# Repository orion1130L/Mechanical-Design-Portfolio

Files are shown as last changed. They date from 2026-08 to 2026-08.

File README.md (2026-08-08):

# Mechanical-Design-Portfolio
# 个人机械设计作品集

本仓库收录了我独立完成的机械系统设计项目。

## 项目一：平行连杆夹爪

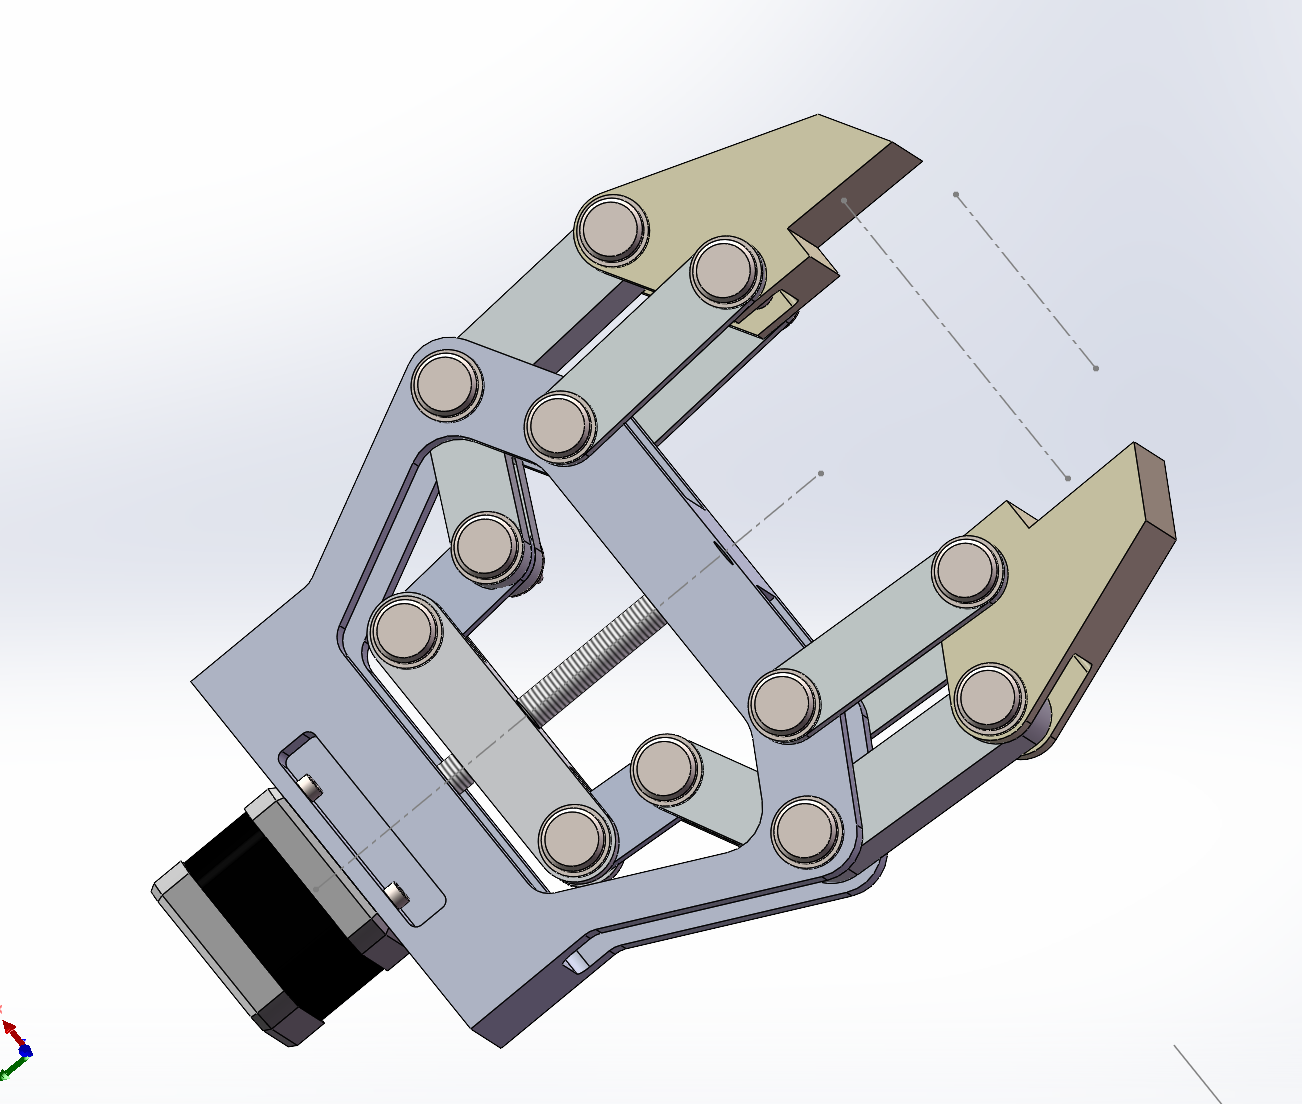
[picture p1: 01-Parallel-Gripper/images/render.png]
夹爪渲染图


- **技术方案**：四杆联动机构 + NEMA17步进电机丝杠驱动
- **设计成果**：行程50-80mm，额定夹持力32.6N，整机安全系数2.5
- **关键工作**：运动学优化、紧固件选型校核、静力学仿真验证

[查看完整设计报告](./01-Parallel-Gripper/docs/机械平行夹爪说明书.pdf)
[查看模型](./01-Parallel-Gripper/models/assembly.IGS) | 通用格式，所有CAD软件可打开 |
## 项目二：滤筒壳体

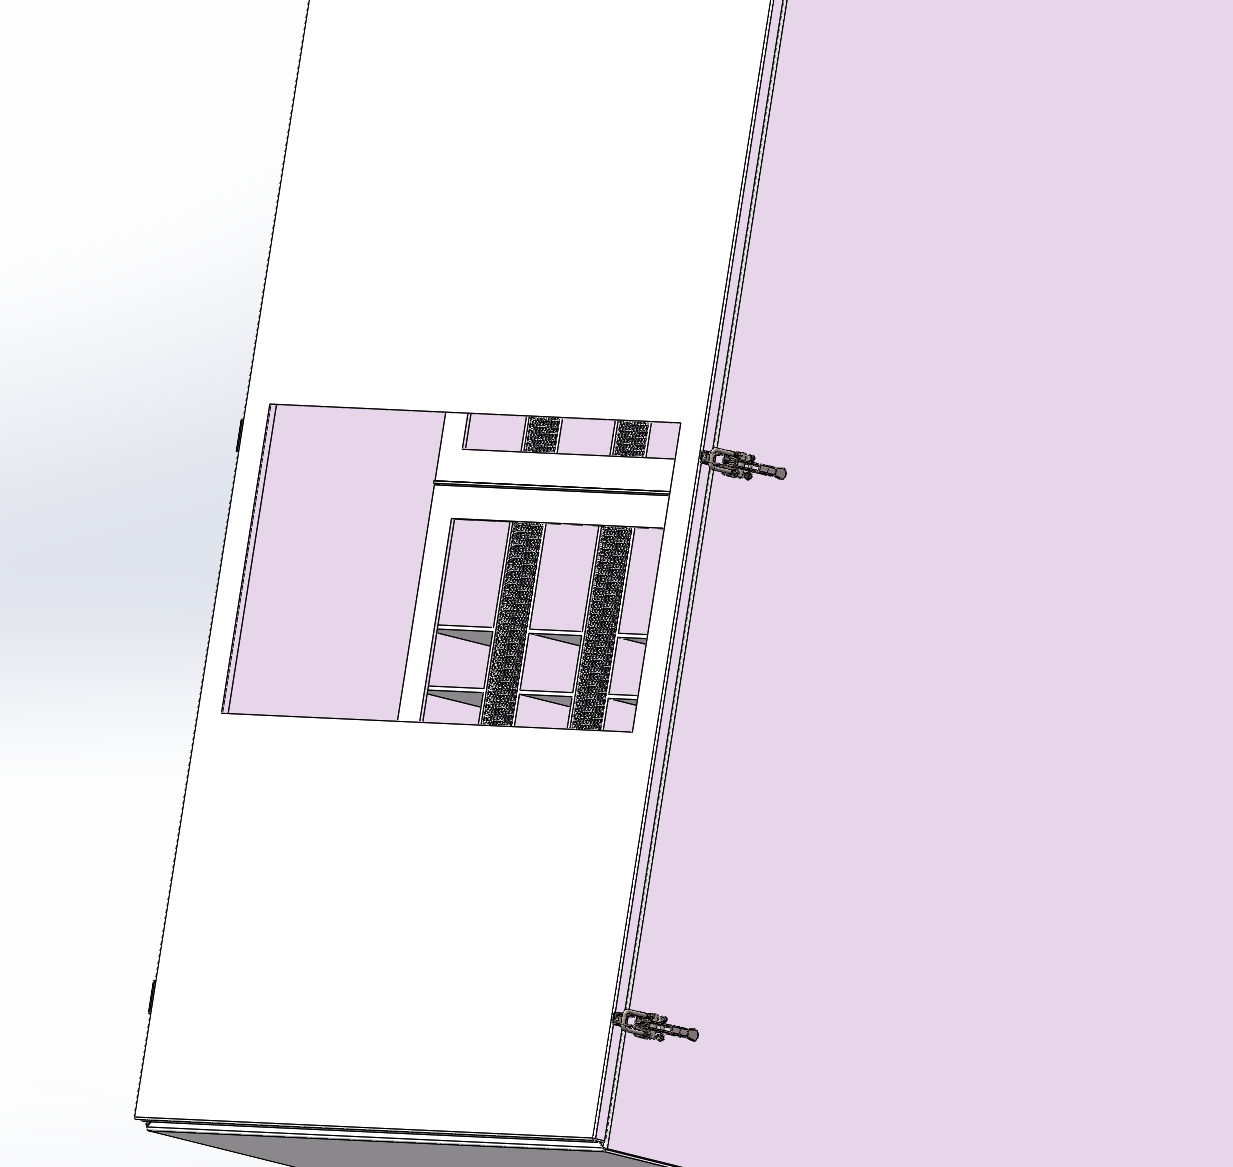
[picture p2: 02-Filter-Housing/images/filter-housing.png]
滤筒壳体


## 关于我

机械工程背景，对机器人末端执行器与柔顺机构设计感兴趣。

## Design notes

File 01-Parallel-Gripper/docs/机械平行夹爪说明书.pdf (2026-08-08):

## 机械平行夹爪说明书

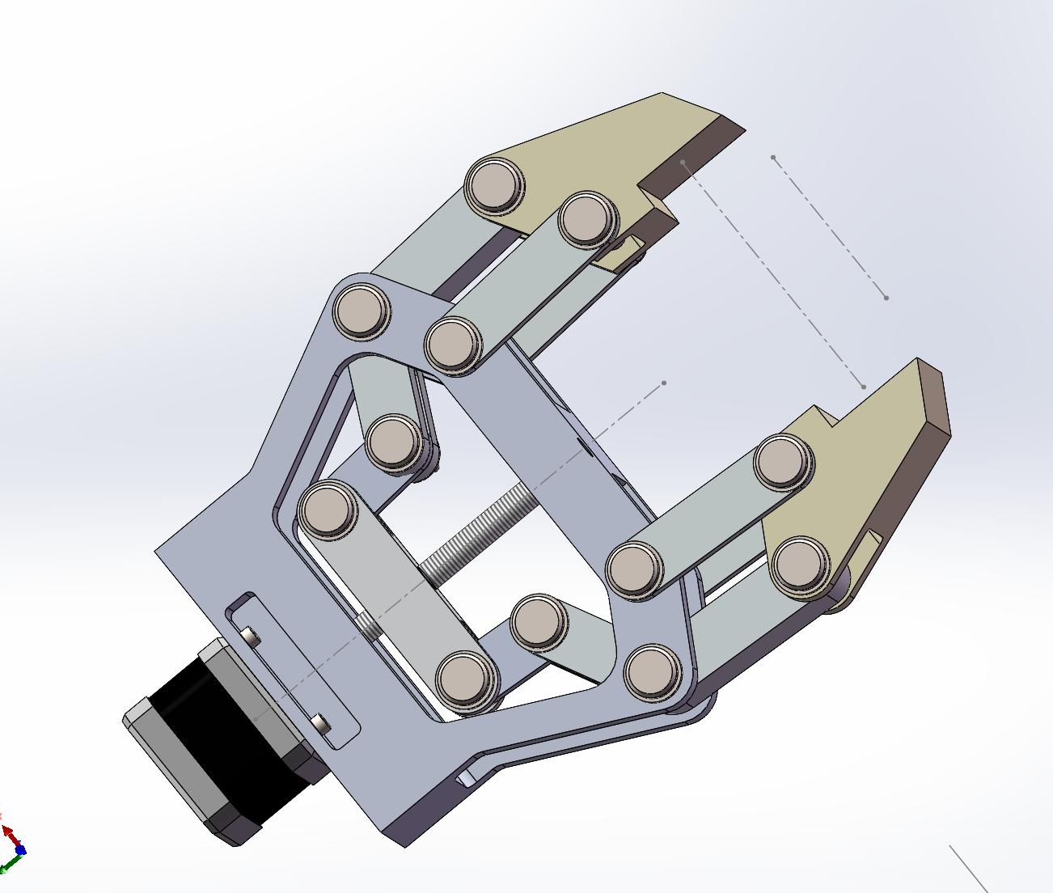
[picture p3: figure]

一，项目名称：桌面级高精度平行连杆夹爪研发

技术方案：采用四杆联动机构与步进电机丝杠一体化传动设计。

核心功能：该项目旨在设计一款具备高重复定位精度的平行开合夹

爪，抓取行程覆盖 50mm 至 80mm。通过 NEMA 17 线性执行器（丝

杠电机）驱动，实现了结构紧凑化设计。项目重点解决了连杆机构

的运动学仿真、标准件选型冗余校核以及复杂装配环境下的紧固连

接可靠性问题。

二，项目职责：

1. 机构建模与运动学优化：使用 SolidWorks 完成全系统参数化建

模。通过理论推导与仿真校核，将连杆中心距从理论值 59.968mm

优化圆整为 60mm，在保证平行开合精度的前提下，显著降低了零件

的机加工工艺难度（DFM 优化）。

2. 紧固与传动系统设计：独立完成驱动端装配方案设计。针对

12.6mm 的大厚度叠层结构，通过紧固件堆叠分析，舍弃了导致结构

薄弱的深沉头设计，选定 ISO 4762 M3x16 规格螺钉。

3. 装配可行性评估：针对旋转关节的轴向限位问题，进行了三轮尺

寸迭代。通过对平垫圈与开口销孔位的空间包络分析，将销轴长度

精确定义为 35mm，确保了装配过程的便捷性与长期运行的维护可靠

性。

三，项目业绩：

1. 设计标准化与工程化：实现了全机标准件 100% 遵循 ISO/GB 标

准规范，显著提升了 BOM 清单的采购兼容性与后期维护的互换性。

2. 关键连接点安全校核：精确控制电机端螺纹啮合深度为 3.4mm

（约 1.1D），在确保连接强度的同时，实现了螺钉末端与电机内部

定子线圈的安全避让，从设计源头规避了电气损毁风险。

3. 技术文档交付：独立完成了包含爆炸图、物料清单 (BOM) 及关

键零件加工图在内的完整技术包，展示了从概念设计到可制造化全

流程掌控能力。

【附录 A：抓取目标与材料选型】

1. 目标工况定义

抓取对象：以标准金属圆柱加工件 / 3C 制造产线电机外壳为例

尺寸范围：外径 Φ60mm ~ Φ70mm（落入 50 ~ 80mm 的有效行程

区）

额定负载质量 (M)：1.0kg

2. 核心部件材料分配

夹爪指尖：表面贴附聚氨酯 (PU) 橡胶软垫（静摩擦系数取 0.3），

提供防滑及微量形变保护。

平行连杆机构：选用 6061-T6 铝合金（CNC 加工），具备优异的屈

服强度与较低的质量，中心孔铰制 Φ8 H7 精度。

固定底座：选用 PETG 或 PA12 工业级树脂 3D 打印，满足厚度结

构的刚度要求。

【附录 B：夹持力学与摩擦力校核】

以标准金属圆柱加工件 / 3C 制造产线电机外壳为例，计算夹持

1kg 负载所需的目标力，并引入动载安全系数。

1. 重力计算

G = M * g = 1kg * 9.8m/s^2 = 9.8N

2. 所需静摩擦力与法向夹紧力

两侧夹爪提供的静摩擦力总和必须大于等于重力。单侧需提供的摩

擦力为 f = 4.9N。

基于 PU 橡胶与金属的摩擦系数 0.3，计算单侧理论法向夹紧力：

理论夹紧力 = f / 0.3 = 4.9N / 0.3 ≈ 16.3N

3. 工程安全余量校核

考虑到机械臂末端可能存在高加速度抖动，引入动载安全系数 K =

2.0。

实际所需夹持力 = 理论夹紧力 * 2.0 = 16.3N * 2.0 = 32.6N

结论：夹爪末端需至少输出 32.6N 的单侧夹持力。

【附录 C：动力传动与步进电机扭矩反推】

该夹爪采用 NEMA 17 一体化丝杠步进电机（匹配梯形丝杠，导程

P=2mm）。通过虚功原理及螺旋传动方程，结合实际三维模型测得的

运动学参数，反推所需的电机保持扭矩。

1. 连杆推力转换（基于实际工作位姿）

根据 SolidWorks 模型实际测定，在设定的极限抓取姿态下，滑块

轴向位移量 Δx = 5.53mm 时，单侧指尖横向位移量 Δy = 15mm。

此时机构的位移传动比：Δy / Δx = 15 / 5.53 ≈ 2.712

根据虚功原理（忽略摩擦损耗），输入功等于总输出功。驱动丝杠需

提供的总轴向推力为：

轴向推力 = 2 * 实际所需夹持力 * (Δy / Δx)

轴向推力 = 2 * 32.6N * 2.712 = 176.8N

2. 螺旋传动扭矩计算

将轴向直线推力转化为电机的旋转扭矩。查阅梯形丝杠传动设计手

册，取传动效率为 0.35。

所需扭矩 = (轴向推力 * 导程) / (2 * 3.14 * 传动效率)

所需扭矩 = (176.8N * 0.002m) / (2 * 3.14 * 0.35) ≈ 0.161

N·m

3. 选型闭环结论

理论需求值：在极限满载且处于最费力传动比（2.712）的工况下，

机构需电机输出 0.161 N·m 的运行扭矩。

实际供给值：本设计选用的 40mm 机身长 NEMA 17 步进电机，其额

定保持扭矩约为 0.40 N·m。

安全系数闭环：0.40 / 0.161 ≈ 2.48 倍。

最终判定：本机构在最恶劣工况下的动力系统依然存在近 2.5 倍的

安全冗余。整机驱动系统校核合格，从根本上杜绝了因负载波动导

致电机“丢步”或堵转的工程风险。一. 设计背景与目标 (Design

Requirements)

【附录 D：概念设计】

平行四边形原理：采用双对称平行四边形连杆结构。相比单连杆，

该结构能确保抓取面受力均匀，避免在抓取轻薄物体时产生滑脱。

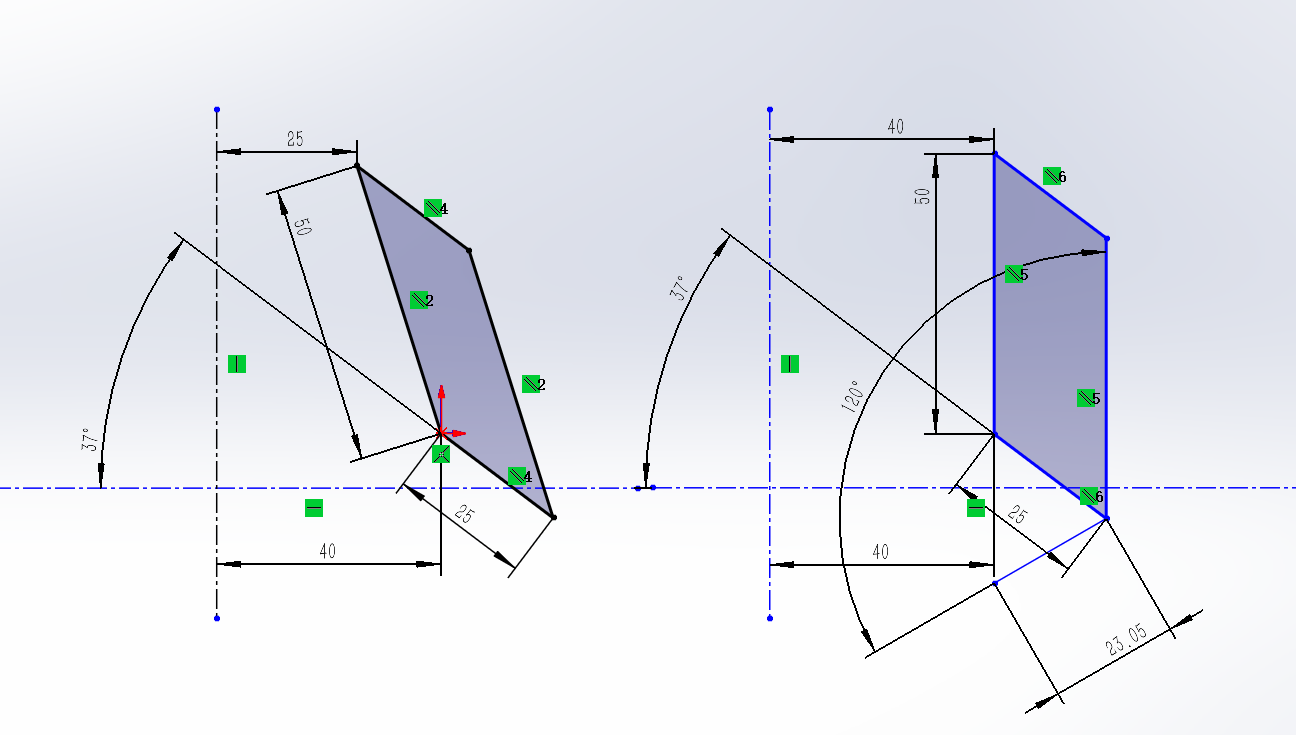
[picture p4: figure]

【附录 E：应力分析】

1，针对受力最苛刻的夹爪指尖(6061 铝合金)，在 32.6N 额定极限

夹持力下进行单体静力学仿真。

边界条件设定:顶部两连接孔采用固定铰链约束，模拟销轴承载状

态。

应力分析结果:最大应力发生于上端销孔内壁(约 7.58MPa)，远低于

6061 铝合金的屈服强度(55.15 MPa).

校核结论:结构安全系数高达 7.2，具备充足的刚度与强度冗余，彻

底排除指尖断裂或塑性变形风险，满足高频工业抓取需求。

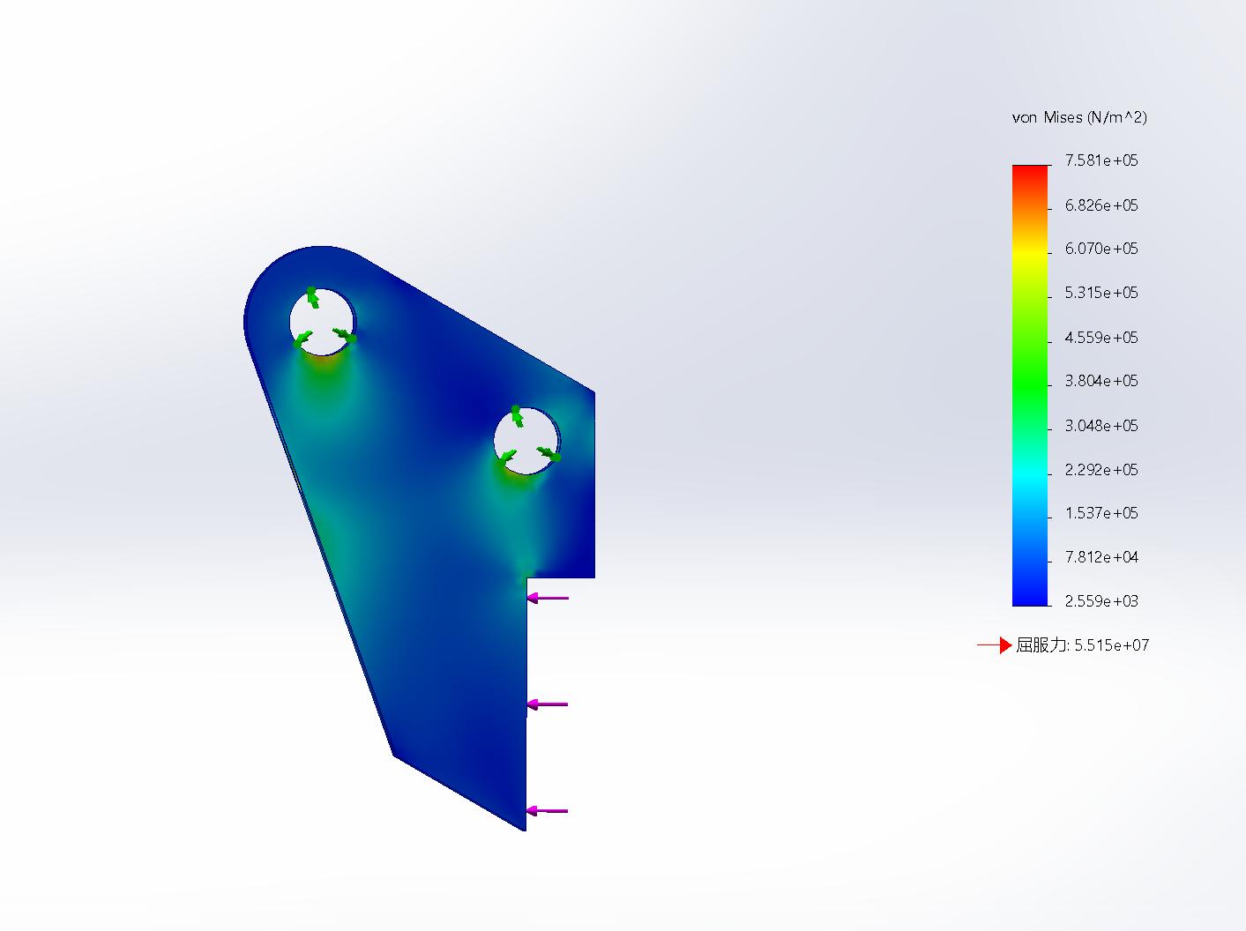
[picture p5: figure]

2.滑块静力学仿真验证

在施加 176.8N 的满载轴向推力工况下，对中心传动滑块进行了应力

分析。仿真结果表明:

应力集中主要出现在中心传力螺纹孔根部，符合载荷传递规律。

全局最大等效应力为 11.03MPa。

对比 6061-T6 铝合金 275MPa 的屈服强度，该零件在满载下的安全系

数高达 25。结论:结构刚度完全满足要求，无疲劳或屈服失效风

险。后期若需整机轻量化，该处横梁厚度仍有极大的优化(掏空/减

薄)空间

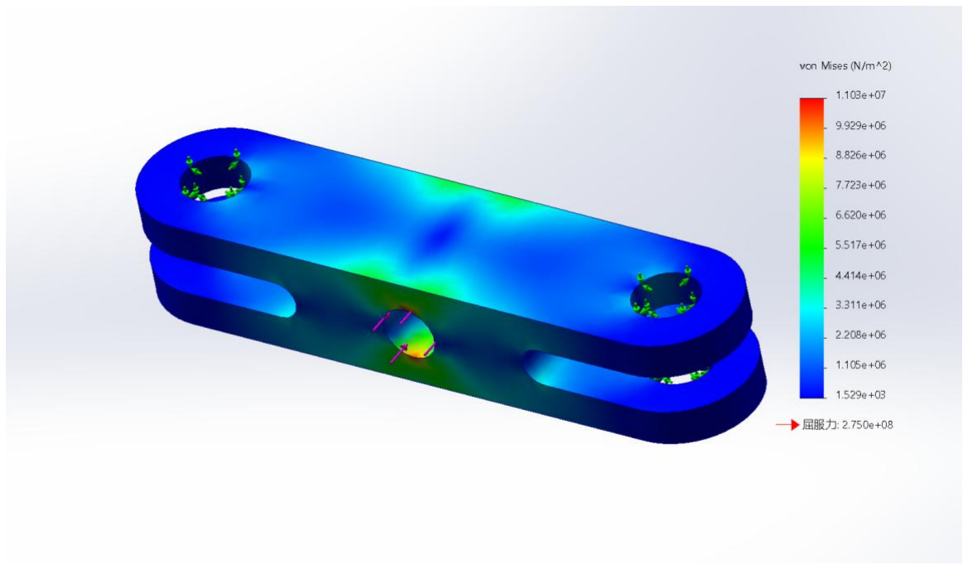
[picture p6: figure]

3，在施加 80N 的满载轴向推力工况下，对关键零件 1 号连杆进行了

应力分析

仿真结果表明:

全局最大等效应力为 81.01MPa。

对比 6061-T6 铝合金 275MPa 的屈服强度，该零件在满载下的安全系

数为 3，下端孔合力为 115N，符合爪头受力要求

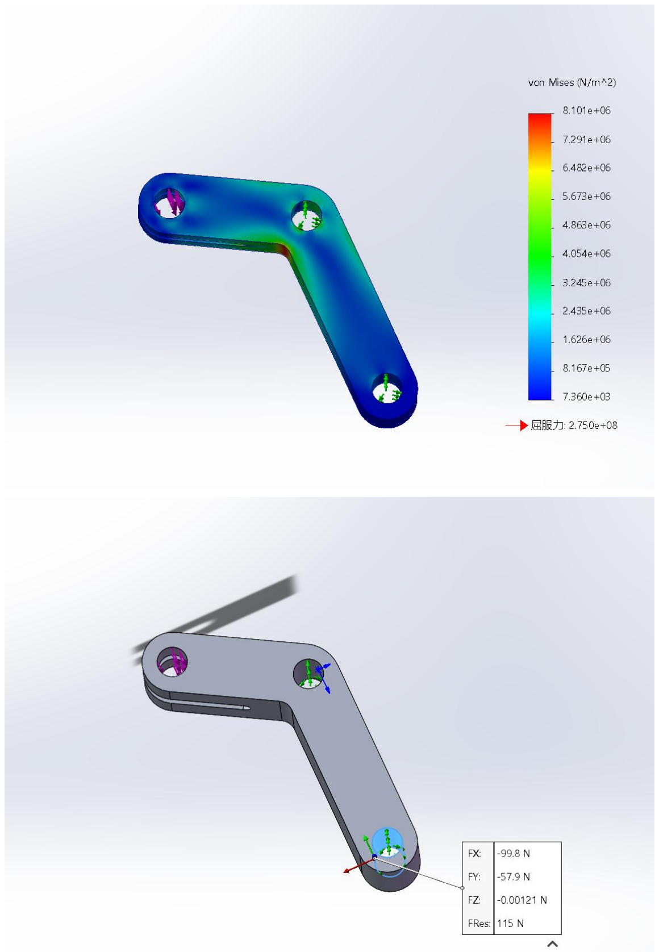
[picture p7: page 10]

【附录 F：爆炸图】

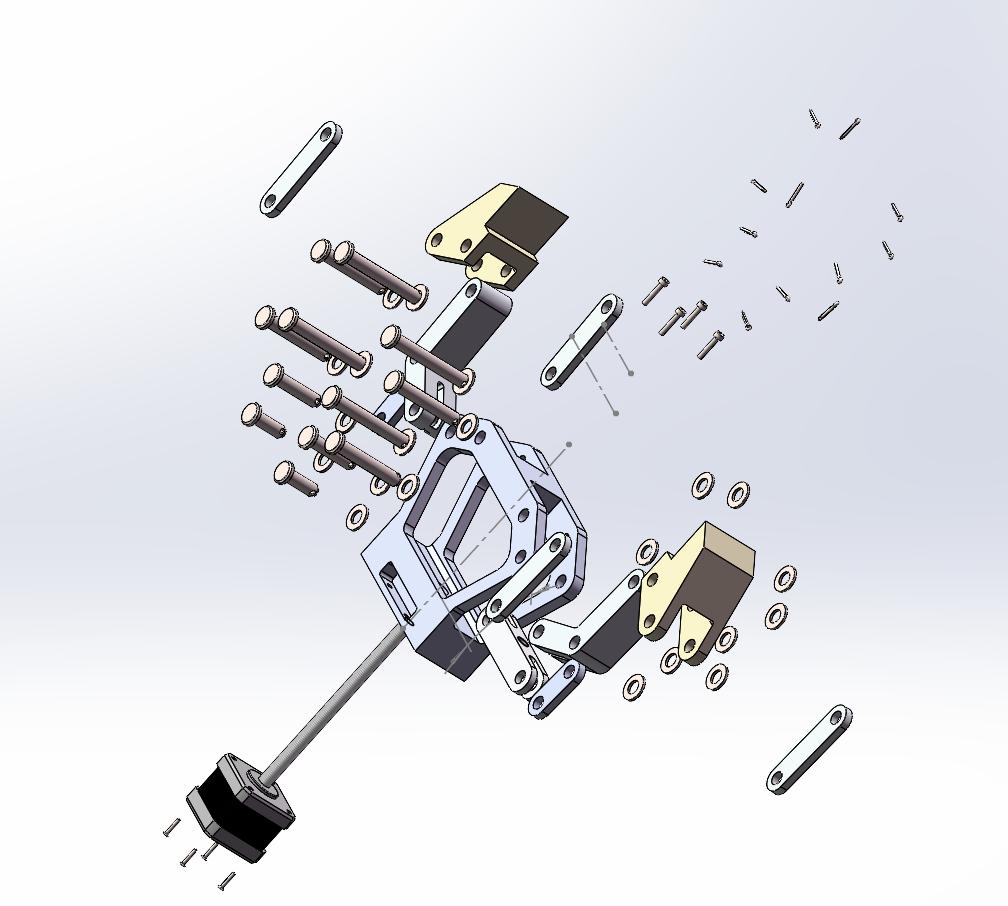
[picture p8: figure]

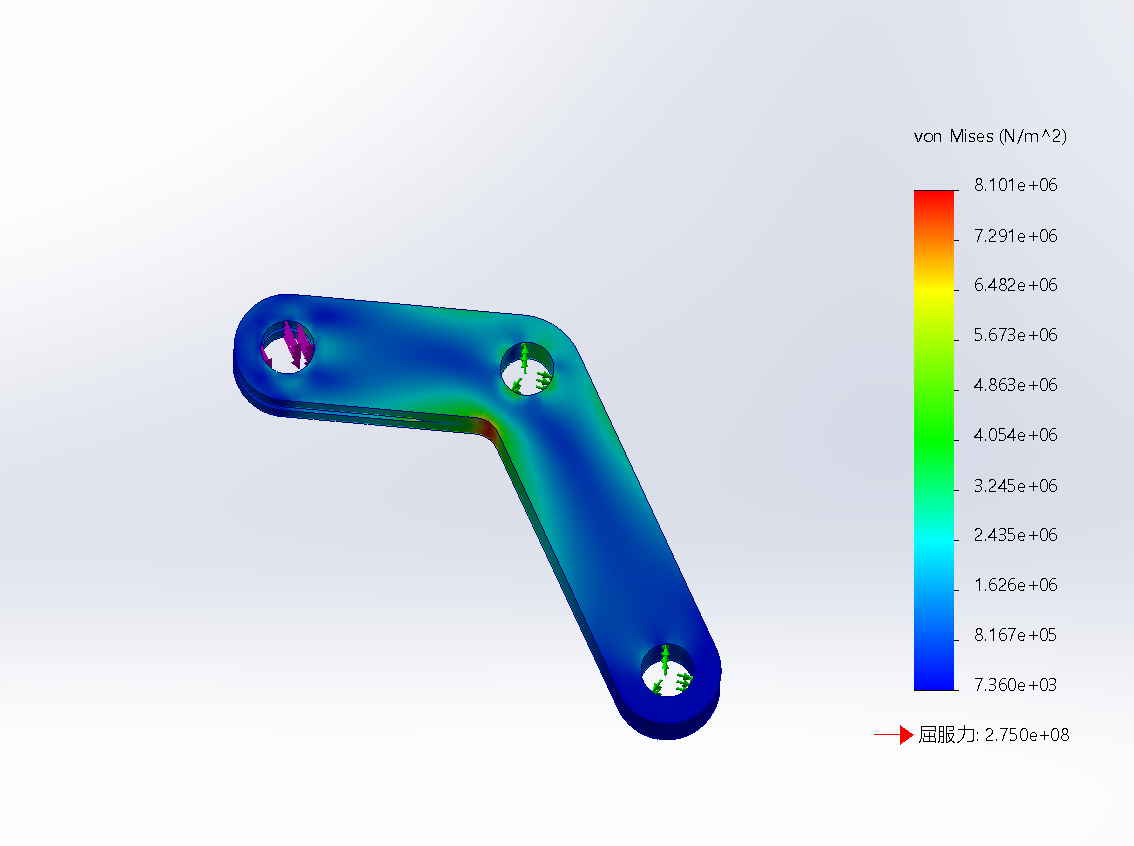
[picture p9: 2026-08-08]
01-Parallel-Gripper/simulations/connecting rod.png

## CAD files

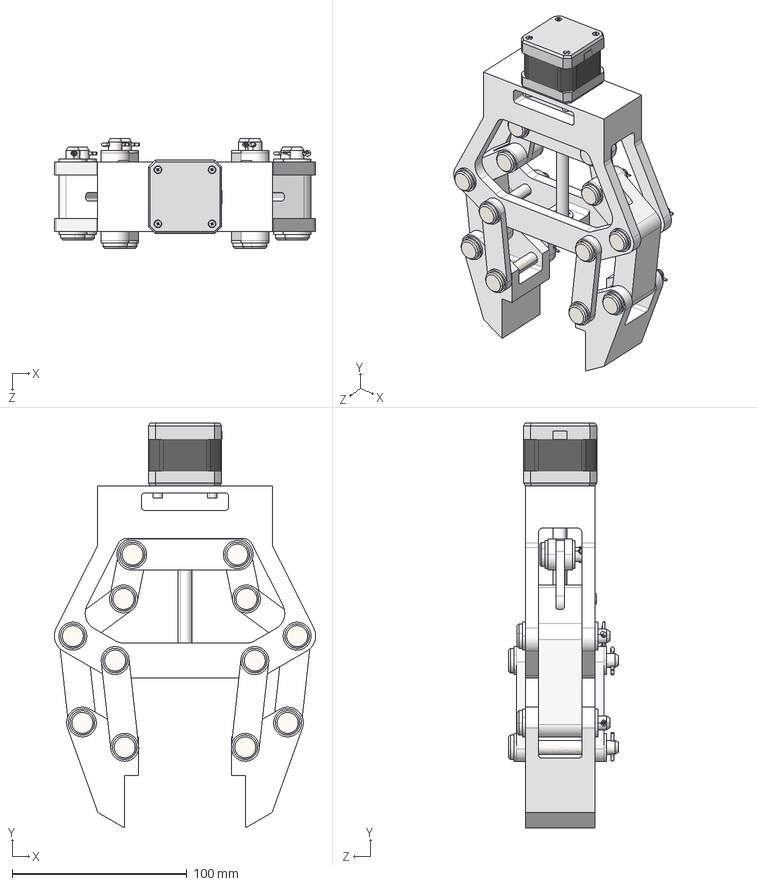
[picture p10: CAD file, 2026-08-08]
01-Parallel-Gripper/models/assembly.IGS
149.7 x 232.0 x 63.0 mm

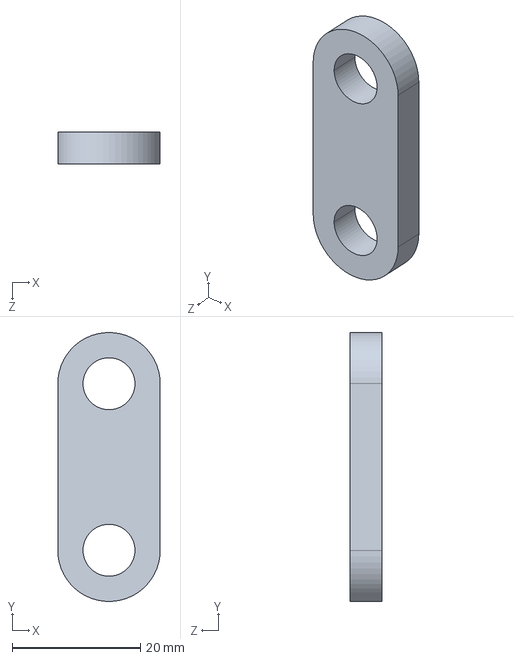
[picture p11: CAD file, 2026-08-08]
01-Parallel-Gripper/models/connecting rod3.STEP
16.0 x 42.0 x 5.00 mm

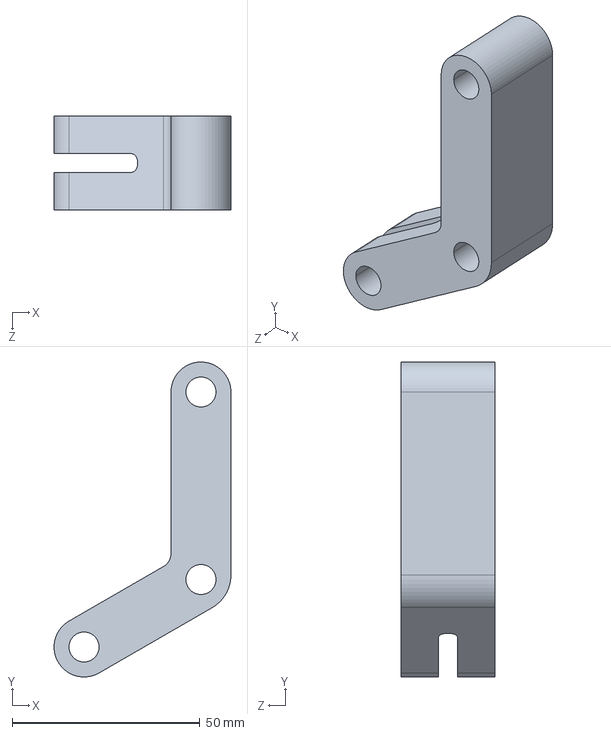
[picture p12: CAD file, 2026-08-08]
01-Parallel-Gripper/models/connecting rod1.STEP
47.2 x 84.0 x 25.0 mm

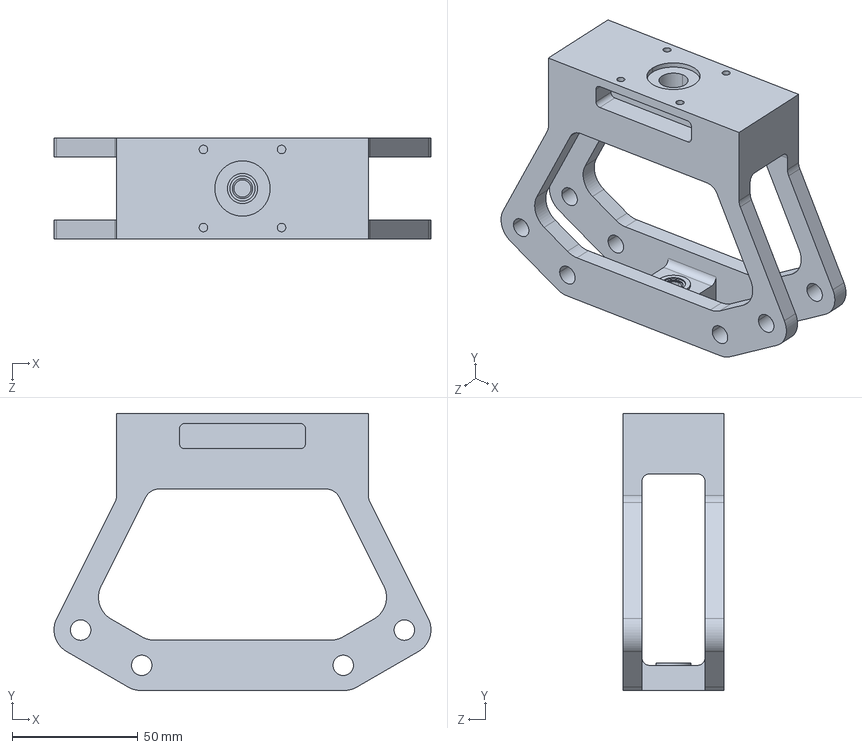
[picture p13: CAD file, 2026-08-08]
01-Parallel-Gripper/models/base.STEP
149.7 x 110.0 x 40.0 mm

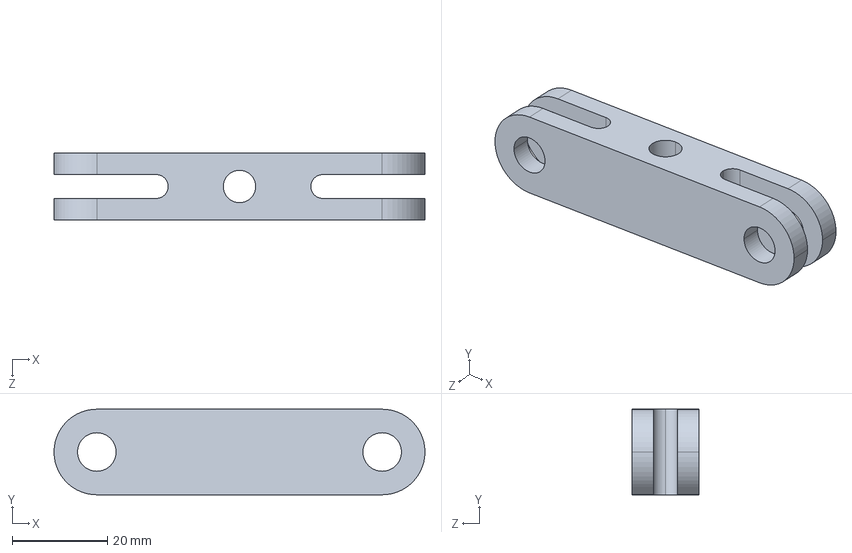
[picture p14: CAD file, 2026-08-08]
01-Parallel-Gripper/models/slider.STEP
78.0 x 18.0 x 14.0 mm

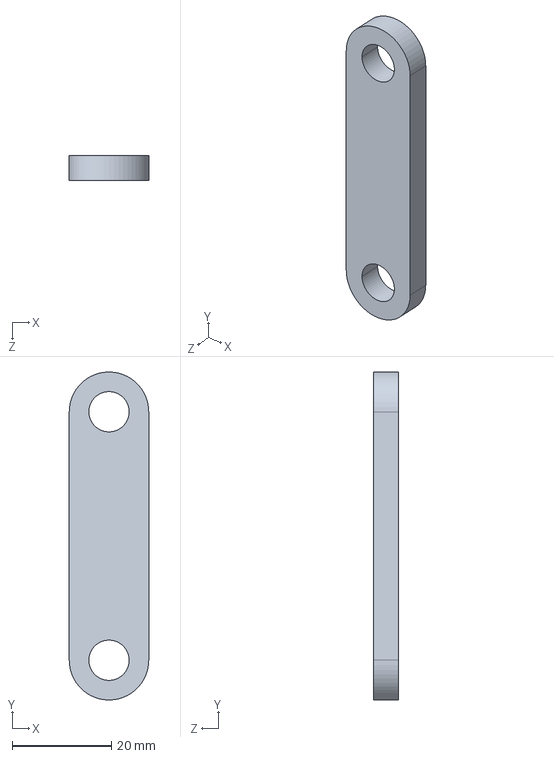
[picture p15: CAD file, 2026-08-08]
01-Parallel-Gripper/models/connecting rod2.STEP
16.0 x 66.0 x 5.00 mm

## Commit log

2026-08-08 Add files via upload
    添加夹爪项目设计报告
2026-08-08 Create 02-Filter-Housing
